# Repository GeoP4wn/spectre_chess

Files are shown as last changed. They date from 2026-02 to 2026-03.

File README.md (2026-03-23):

# Spectre Chess
---
## Overview
---
This is very much still a work in progress. The best place to start is the technical report (particularly the pictures at the end of the document) and the other documents in the docs folder.

This project is designed to be a robotic chessboard constrained to an external height of 60mm. It features an H-bot gantry to move an electromagnet, which in turn moves the chess pieces.
The main computing is done by a Raspberry Pi. The Raspberry Pi controls two ESP32s. One is responsible for the motors and magnets, the other is responsible for the sensors, LEDs and buttons.

AI Disclosure: Generative AI was used to build the basic structure and async loop of the codebase

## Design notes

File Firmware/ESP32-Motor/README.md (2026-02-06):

# ESP32 Motor Controller Firmware

## Overview
This firmware runs on the ESP32-S3 responsible for H-Bot gantry control, electromagnet actuation, and fan management.

## Hardware Responsibilities
- ✅ Control 2x TMC2209 stepper drivers (H-Bot kinematics)
- ✅ Home gantry using limit switch
- ✅ Control 4x electromagnets via MOSFETs
- ✅ PWM control of 4x cooling fans
- ✅ Communicate with Raspberry Pi via UART (JSON protocol)

## Pin Assignments

### Stepper Motors (TMC2209)
| Pin | Function | Description |
|-----|---|---|
| GPIO2 | MOTOR_A_STEP | Step pulses for Motor A |
| GPIO3 | MOTOR_A_DIR | Direction for Motor A |
| GPIO4 | MOTOR_A_EN | Enable for Motor A (active LOW) |
| GPIO5 | MOTOR_A_UART | Single-wire UART (with 1kΩ resistor) |
| GPIO6 | MOTOR_B_STEP | Step pulses for Motor B |
| GPIO7 | MOTOR_B_DIR | Direction for Motor B |
| GPIO8 | MOTOR_B_EN | Enable for Motor B (active LOW) |
| GPIO9 | MOTOR_B_UART | Single-wire UART (with 1kΩ resistor) |

### Electromagnets (MOSFET Control)
| Pin | Function | Description |
|-----|---|---|
| GPIO16 | MAGNET_1 | Electromagnet 1 gate (via 10kΩ pulldown) |
| GPIO17 | MAGNET_2 | Electromagnet 2 gate |
| GPIO18 | MAGNET_3 | Electromagnet 3 gate |
| GPIO19 | MAGNET_4 | Electromagnet 4 gate |

### Limit Switch
| Pin | Function | Description |
|-----|---|---|
| GPIO32 | LIMIT_SWITCH | Homing limit switch (active LOW) |

### Fans (PWM Control)
| Pin | Function | Description |
|-----|---|---|
| GPIO25 | FAN_1 | Fan 1 PWM (via level shifter to 5V) |
| GPIO26 | FAN_2 | Fan 2 PWM |
| GPIO27 | FAN_3 | Fan 3 PWM |
| GPIO33 | FAN_4 | Fan 4 PWM |

### UART Communication
| Pin | Function | Description |
|-----|---|---|
| GPIO1 (RX) | UART_RX | Receive from Raspberry Pi |
| GPIO3 (TX) | UART_TX | Transmit to Raspberry Pi |

## Dependencies
```ini
bblanchon/ArduinoJson@^6.21.3
teemuatlut/TMCStepper@^0.7.3
```

## H-Bot Kinematics Explained

### What is H-Bot?
H-Bot is a motion system where **both motors affect both X and Y axes**. Unlike traditional XY systems where one motor moves X and another moves Y, H-Bot uses a clever belt arrangement.

### Motor Coordination
```
To move +X: Motor A forward + Motor B forward
To move +Y: Motor A forward + Motor B backward
To move -X: Motor A backward + Motor B backward
To move -Y: Motor A backward + Motor B forward
```

### Mathematical Model
```
stepsA = stepsX + stepsY
stepsB = stepsX - stepsY
```

Inverse:
```
stepsX = (stepsA + stepsB) / 2
stepsY = (stepsA - stepsB) / 2
```

### Advantages
- ✅ Low moving mass (motors are stationary)
- ✅ Compact vertical profile (both belts in same plane)
- ✅ Good for speed and precision
- ✅ Perfect for our <45mm height constraint

### Disadvantages
- ⚠️ More complex firmware
- ⚠️ Requires synchronized motor control
- ⚠️ Belt tension is critical

## Communication Protocol

### Messages FROM ESP32 to Pi

#### Status
```json
{
  "type": "status",
  "status": "ready",
  "controller": "motor",
  "message": "Motor controller initialized"
}
```

```json
{
  "type": "status",
  "status": "homed",
  "controller": "motor",
  "message": "Gantry homed to (0, 0)"
}
```

#### Position Update
```json
{
  "type": "position",
  "x": 165.5,
  "y": 220.0,
  "homed": true
}
```

### Messages TO ESP32 from Pi

#### Home Gantry
```json
{
  "cmd": "home"
}
```

#### Move to Absolute Position
```json
{
  "cmd": "move_absolute",
  "x": 200.0,
  "y": 150.0,
  "speed": 5000
}
```

#### Move Relative
```json
{
  "cmd": "move_relative",
  "dx": 10.0,
  "dy": -5.0
}
```

#### Electromagnet Control
Turn on specific magnet:
```json
{
  "cmd": "magnet_on",
  "magnet": 1
}
```

Turn on all magnets:
```json
{
  "cmd": "magnet_on"
}
```

Turn off:
```json
{
  "cmd": "magnet_off",
  "magnet": 1
}
```

#### Fan Control
```json
{
  "cmd": "set_fan",
  "fan": 1,
  "speed": 200
}
```

#### Emergency Stop
```json
{
  "cmd": "stop"
}
```

#### Get Current Position
```json
{
  "cmd": "get_position"
}
```

## TMC2209 Configuration

### Current Settings
- **Run current**: 500mA RMS (for 0.7A NEMA17)
- **Hold current**: 200mA RMS (reduced when stationary)
- **Microstepping**: 16 (1/16 step)
- **Mode**: StealthChop (silent operation)

### Why StealthChop?
- 🔇 Near-silent operation
- ✅ Smooth motion at low speeds
- ✅ No tuning required
- ⚠️ Less torque at very high speeds (not an issue for chess board)

### UART Communication
TMC2209 uses **single-wire half-duplex UART**:
- 1kΩ resistor on RX pin prevents short circuit
- ESP32 TX and RX share same pin via resistor
- Address switches (MS1_AD0, MS2_AD1 on driver):
  - Motor A: Address 0b00
  - Motor B: Address 0b01

## Motor Calibration

### Steps Per MM Calculation
```
Pulley diameter: 20 teeth × 2mm = 40mm circumference
Belt pitch: GT2 (2mm)
Circumference: 40mm × π ≈ 125.66mm

Steps per revolution: 200 (1.8° stepper)
Microstepping: 16
Total steps per rev: 200 × 16 = 3200 steps

Steps per mm: 3200 / 125.66 ≈ 25.5 steps/mm
```

**Default in firmware: 80 steps/mm** (adjust based on your actual pulley size)

### Speed Settings
- **Default speed**: 2000 steps/sec (≈78mm/sec with 25.5 steps/mm)
- **Max speed**: 8000 steps/sec (≈314mm/sec)
- **Homing speed**: 500 steps/sec (slower for safety)

## Homing Sequence

1. **Move towards limit switch** (both motors reverse)
2. **Wait for trigger** (limit switch goes LOW)
3. **Stop immediately**
4. **Back off 100 steps** (move away from switch)
5. **Set position to (0, 0)**
6. **Mark as homed**

## Electromagnet Circuit

### MOSFET Switching
- **MOSFET**: IRFL44N (N-channel, logic level)
- **Gate resistor**: 10kΩ pulldown (prevents firing during boot)
- **Flyback diode**: 1N4007 (protects against back-EMF)
- **Load**: P25/20 electromagnet (12V, ~1A)

### Control Logic
```
GPIO HIGH (3.3V) → MOSFET ON → Magnet energized
GPIO LOW (0V)    → MOSFET OFF → Magnet off
```

### Why Pulldown?
During ESP32 boot, GPIOs are in high-impedance state. Without pulldown, the gate could float HIGH and accidentally energize magnets. The 10kΩ pulldown ensures MOSFET stays OFF until explicitly commanded.

## Building and Uploading

### Using PlatformIO CLI
```bash
cd ESP32-Motor
pio run --target upload
pio device monitor
```

### Using PlatformIO IDE
1. Open folder in VS Code with PlatformIO extension
2. Click "Upload" button
3. Click "Serial Monitor" button

## Testing

### 1. Basic Boot Test
After upload, check serial monitor:
```
=== ESP32 Motor Controller Starting ===
Configuring TMC2209 drivers...
TMC2209 drivers configured
Driver A current: 500
Driver B current: 500
Pins configured
Setup complete. Ready for commands.
```

### 2. Driver Communication Test
Verify TMC2209 UART is working:
- Check "Driver A current: 500" appears
- If shows 0 or error, check UART wiring

### 3. Manual Movement Test (NO LOAD)
**⚠️ Remove belt before this test!**

Send via Serial Monitor:
```json
{"cmd":"move_absolute","x":10,"y":0,"speed":1000}
```

Motors should turn slowly.

### 4. Homing Test
**WITH limit switch connected:**
```json
{"cmd":"home"}
```

Should see:
```
Starting homing sequence...
Limit switch triggered
Homing complete
```

### 5. Electromagnet Test
```json
{"cmd":"magnet_on","magnet":1}
```

Should hear relay/magnet click. Verify with multimeter: 12V across magnet.

### 6. Fan Test
```json
{"cmd":"set_fan","fan":1,"speed":200}
```

Fan should spin up.

## Troubleshooting

### Motors don't move
1. **Check enable pins** - Should be LOW to enable
2. **Check TMC2209 power** - Need 12V to VM pin
3. **Check UART communication** - Should see current readback
4. **Check motor wiring** - Coil pairs must be correct

### Motors move wrong direction
Swap direction logic in firmware or physically swap one coil pair.

### Homing doesn't work
1. **Test limit switch** - Should read HIGH when open, LOW when closed
2. **Check direction** - Motors should move toward switch
3. **Verify switch is in (0,0) corner**

### Electromagnets won't turn on
1. **Check 12V power supply**
2. **Verify MOSFET orientation** - Drain to +12V, Source to magnet
3. **Test GPIO directly** - Should read 3.3V when on
4. **Check flyback diode** - Stripe toward +12V

### TMC2209 gets hot
- Reduce current: `driverA.rms_current(400);`
- Add heatsink to driver
- Verify motor current rating

### Motors skip steps
- Increase current (up to motor rating)
- Reduce speed
- Check belt tension
- Verify acceleration isn't too high

## Calibration Procedure

### 1. Mechanical Setup
- Ensure belts are properly tensioned (should "twang" when plucked)
- Verify pulleys are tight on motor shafts
- Check that gantry moves smoothly by hand

### 2. Steps/MM Calibration
```cpp
// In firmware, adjust STEPS_PER_MM
#define STEPS_PER_MM  80  // Start here

// Test: Command 100mm movement
{"cmd":"move_absolute","x":100,"y":0}

// Measure actual distance traveled
// Adjust STEPS_PER_MM = (commanded / actual) * current
```

### 3. Speed Tuning
Start slow and increase:
```json
{"cmd":"move_absolute","x":200,"y":200,"speed":1000}
{"cmd":"move_absolute","x":0,"y":0,"speed":2000}
{"cmd":"move_absolute","x":200,"y":200,"speed":5000}
```

Find max speed where no steps are lost.

### 4. Acceleration Tuning
Currently not implemented (constant speed). Future enhancement.

## Power Requirements

- **Motors**: 12V, 0.7A each = 16.8W
- **Electromagnets**: 12V, 1A each × 4 = 48W (worst case, all on)
- **Fans**: 12V, 0.15A each × 4 = 7.2W
- **ESP32**: 3.3V, 0.2A = 0.66W
- **Total**: ~73W at full load

Recommended: **12V 10A power supply** for safety margin.

## Safety Features

### Implemented
- ✅ Position limits (won't move beyond MAX_X_MM, MAX_Y_MM)
- ✅ Homing required before movement
- ✅ Emergency stop command
- ✅ Pulldown resistors on MOSFET gates

### To Add (Future)
- [ ] Stall detection via TMC2209
- [ ] Soft limits
- [ ] Current monitoring
- [ ] Thermal protection
- [ ] Watchdog timer

## Future Enhancements

- [ ] Acceleration/deceleration curves
- [ ] Multi-segment path following
- [ ] Automatic stall recovery
- [ ] Position feedback verification
- [ ] Coordinated multi-axis circular interpolation
- [ ] Backlash compensation

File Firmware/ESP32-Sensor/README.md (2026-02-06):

# ESP32 Sensor Controller Firmware

## Overview
This firmware runs on the ESP32-S3 responsible for sensor scanning, LED control, and button input monitoring.

## Hardware Responsibilities
- ✅ Scan 64 Hall Effect sensors (8x8 matrix) via 4x CD74HC4067 multiplexers
- ✅ Control 64 WS2812B RGB LEDs for board visualization
- ✅ Read 6 physical buttons
- ✅ Read 2 rotary encoders with buttons
- ✅ Communicate with Raspberry Pi via UART (JSON protocol)

## Pin Assignments

### Multiplexer Control (Shared)
| Pin | Function | Description |
|-----|---|---|
| GPIO2 | MUX_S0 | Multiplexer select bit 0 (all 4 muxes) |
| GPIO3 | MUX_S1 | Multiplexer select bit 1 |
| GPIO4 | MUX_S2 | Multiplexer select bit 2 |
| GPIO5 | MUX_S3 | Multiplexer select bit 3 |
| GPIO16 | MUX_EN | Multiplexer enable (active LOW) |

### Multiplexer Outputs
| Pin | Function | Handles |
|-----|---|---|
| GPIO17 | MUX1_OUT | Ranks 0-1 (squares a1-h2) |
| GPIO18 | MUX2_OUT | Ranks 2-3 (squares a3-h4) |
| GPIO19 | MUX3_OUT | Ranks 4-5 (squares a5-h6) |
| GPIO21 | MUX4_OUT | Ranks 6-7 (squares a7-h8) |

### LEDs
| Pin | Function | Description |
|-----|---|---|
| GPIO22 | LED_DATA | WS2812B data line (64 LEDs) |

### Buttons
| Pin | Function | Description |
|-----|---|---|
| GPIO25 | BTN1 | Clock button 1 (top left) |
| GPIO26 | BTN2 | Clock button 2 (top right) |
| GPIO27 | BTN3 | Side button 1 |
| GPIO32 | BTN4 | Side button 2 |
| GPIO33 | BTN5 | Side button 3 |
| GPIO34 | BTN6 | Side button 4 |

### Rotary Encoders
| Pin | Function | Description |
|-----|---|---|
| GPIO35 | ENC1_A | Encoder 1 channel A |
| GPIO36 | ENC1_B | Encoder 1 channel B |
| GPIO39 | ENC1_BTN | Encoder 1 button |
| GPIO14 | ENC2_A | Encoder 2 channel A |
| GPIO12 | ENC2_B | Encoder 2 channel B |
| GPIO13 | ENC2_BTN | Encoder 2 button |

### UART Communication
| Pin | Function | Description |
|-----|---|---|
| GPIO1 (RX) | UART_RX | Receive from Raspberry Pi |
| GPIO3 (TX) | UART_TX | Transmit to Raspberry Pi |

## Dependencies
```ini
adafruit/Adafruit NeoPixel@^1.11.0
bblanchon/ArduinoJson@^6.21.3
```

## Communication Protocol

### Messages FROM ESP32 to Pi

#### Sensor Update
Sent when board state changes.
```json
{
  "type": "sensor_update",
  "sensors": [
    [false, true, true, true, true, true, true, false],
    [true, true, true, true, true, true, true, true],
    [false, false, false, false, false, false, false, false],
    ...
  ]
}
```

#### Button Event
```json
{
  "type": "button",
  "button": 1,
  "state": "pressed"
}
```

#### Encoder Event
```json
{
  "type": "encoder",
  "encoder": 1,
  "delta": -2
}
```

#### Status
```json
{
  "type": "status",
  "status": "ready",
  "controller": "sensor"
}
```

### Messages TO ESP32 from Pi

#### Scan Sensors
Request immediate sensor scan.
```json
{
  "cmd": "scan_sensors"
}
```

#### Highlight Squares
Light up specific squares.
```json
{
  "cmd": "highlight_squares",
  "squares": [[3, 4], [4, 4]],
  "color": [0, 255, 0],
  "duration": 2000
}
```

#### Flash All LEDs
Flash all LEDs (error indication).
```json
{
  "cmd": "flash_all",
  "color": [255, 0, 0],
  "count": 3
}
```

#### Set LED Theme
```json
{
  "cmd": "set_theme",
  "theme": "classic"
}
```

#### LEDs Off
```json
{
  "cmd": "leds_off"
}
```

#### Set Brightness
```json
{
  "cmd": "set_brightness",
  "brightness": 128
}
```

## Sensor Scanning Logic

The firmware scans all 64 sensors every 100ms:

1. **Loop through each square** (8x8 = 64 total)
2. **Calculate multiplexer and channel**:
   - Multiplexer index = rank ÷ 2 (0-3)
   - Channel = (rank mod 2) × 8 + file (0-15)
3. **Set channel select pins** (S0-S3)
4. **Read from appropriate MUX output pin**
5. **Invert result** (AH3503 is active LOW)
6. **Compare with last state** - if changed, send update

## LED Layout

LEDs are arranged in a serpentine pattern:
- **Rank 0** (a1-h1): Left to right (indices 0-7)
- **Rank 1** (a2-h2): Right to left (indices 8-15)
- **Rank 2** (a3-h3): Left to right (indices 16-23)
- And so on...

This minimizes wiring length for WS2812B strip.

## Building and Uploading

### Using PlatformIO CLI
```bash
cd ESP32-Sensor
pio run --target upload
pio device monitor
```

### Using PlatformIO IDE
1. Open folder in VS Code with PlatformIO extension
2. Click "Upload" button
3. Click "Serial Monitor" button

## Testing

### 1. Basic Boot Test
After upload, check serial monitor:
```
=== ESP32 Sensor Controller Starting ===
Pins configured
LEDs initialized
Setup complete. Ready for commands.
```

### 2. LED Test
LEDs should flash white briefly on boot.

### 3. Sensor Test
Place a magnet on the board and observe serial output:
```
Sensor update sent
```

### 4. Button Test
Press any button:
```
Button 1 pressed
Button 1 released
```

### 5. UART Test
Send from Pi:
```bash
echo '{"cmd":"scan_sensors"}' > /dev/ttyUSB0
```

Should receive JSON response.

## Troubleshooting

### LEDs don't light up
- Check 5V power supply to LED strip
- Verify data pin connection (GPIO22)
- Ensure ground is common between ESP32 and LED strip

### Sensors not responding
- Verify 5V power to AH3503 sensors
- Check TXS0108E level shifter connections
- Ensure multiplexer enable (GPIO16) is LOW
- Test with multimeter: sensor output should be LOW when magnet present

### No UART communication
- Check TX/RX connections (they should cross: ESP32 TX → Pi RX)
- Verify baud rate matches (115200)
- Test with USB-to-serial adapter first

### Buttons always pressed / never pressed
- Buttons should be active LOW with pullup resistors
- Check wiring: one side to GND, other to GPIO
- Verify internal pullup is enabled

## Hardware Notes

### Level Shifters
The TXS0108E shifts between:
- **A-side (VCCA)**: 3.3V (ESP32 logic)
- **B-side (VCCB)**: 5V (sensor outputs)

Connect sensor outputs to B-side, ESP32 GPIOs to A-side.

### Hall Effect Sensors
AH3503 sensors:
- **Pin 1 (VCC)**: 5V
- **Pin 2 (GND)**: Ground
- **Pin 3 (VOUT)**: Open drain output (active LOW)
  - Needs pull-up resistor to 5V (typically 10kΩ)
  - LOW when magnet present
  - HIGH (pulled up) when no magnet

### Multiplexer Channel Mapping
Each CD74HC4067 handles 16 sensors (2 ranks × 8 files):

**MUX 1** (Ranks 0-1):
- Channel 0-7: a1, b1, c1, d1, e1, f1, g1, h1
- Channel 8-15: a2, b2, c2, d2, e2, f2, g2, h2

**MUX 2** (Ranks 2-3):
- Channel 0-7: a3, b3, c3, d3, e3, f3, g3, h3
- Channel 8-15: a4, b4, c4, d4, e4, f4, g4, h4

And so on for MUX 3 and MUX 4.

## Power Consumption

Estimated current draw:
- ESP32-S3: ~200mA (WiFi off)
- 64x WS2812B LEDs (all white, full brightness): ~3.8A
- Hall Effect sensors: ~64mA
- **Total**: ~4.1A at 5V

Use a quality 5V 5A power supply!

## Future Enhancements

- [ ] Automatic LED animations during idle
- [ ] Configurable scan interval
- [ ] Sensor calibration routine
- [ ] Button long-press detection
- [ ] LED brightness auto-adjustment
- [ ] Power-saving mode

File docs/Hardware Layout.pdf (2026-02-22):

## Raspberry Pi

Hardware | Software
Microphone | Voice Recognition (https://maker.pro/raspberry-pi/tutorial/the-best-voice-recognition-software-for-raspberry-pi)
LCD Screen + Touch | User Interface
| Touch Recognition
| BoardState
| ChessEngine
| UserDatabase
| MoveEvaluation

## Motor ESP32

Hardware | Software
Motor | Fan Control
Electromagnet | ChessMoveToMotorMovement
Fans | ElectromagnetControl

## Sensor ESP32

Hardware | Software
Buttons and Rotary Encoder | ButtonPresses
Hall Effect Sensors | SensorReadOut
LEDs | MoveToLEDLight

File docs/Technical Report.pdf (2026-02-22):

# Automated Chessboard: A Distributed IoT System with H-Bot Kinematics

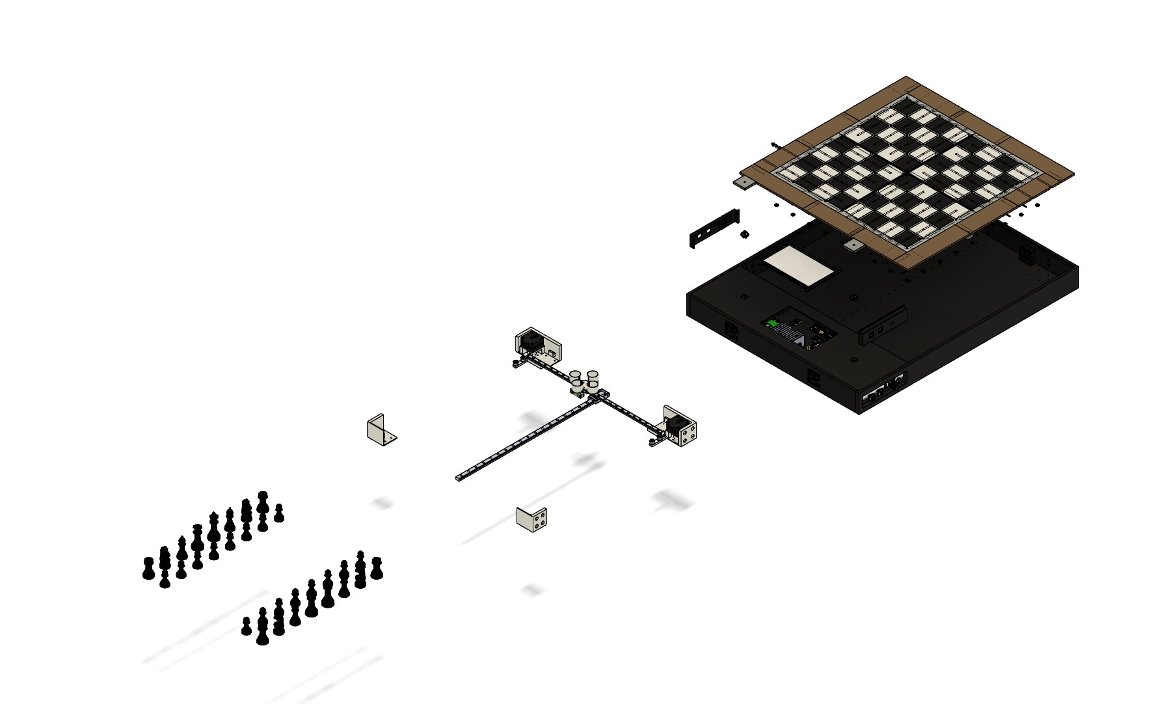
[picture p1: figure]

## Abstract

This report describes the design and implementation of a smart robotic chessboard utilizing an H-Bot gantry system. The system utilizes an H-Bot gantry architecture constrained to an internal 45mm height profile, orchestrating movement via a distributed network of microcontrollers and a single-board computer. Key contributions include a low-friction material interface for 3D-printed surfaces, a custom JSON-over-UART communication protocol, and a local, offline software stack featuring real-time WebSockets and voice recognition.

## Introduction

Traditionally, chess is a game played between two human players. Recent technological advances have enabled to play against chess engines or other humans online. This enables to play chess whenever one likes. However, many people feel a lack of haptic feedback when moving pieces and screeens can be exhausting when used over long periods of times. This was the reason for the developement of smart chess boards. The first step were boards that were able to calculate follow up moves, but changes in the pieces position had to be manually registered by pressing buttons. A novelty were LED chess boards that feautered sensor technology and feedback through LED lights inside of the squares. The most modern form of a smart chess board are fully automatic boards which in adition to sensors also have a mechanical system that moves the chess pieces. This is often achieved by a moving electromagnet and magnets in the bottom of the chess pieces that also trigger reed or hall effect sensors.
Many adaptations from makers all around the world have been made for afore mentioned technology. However most self built gantry systems feature an exterior height of more than 100mm making it impractical to use these boards on common tables. An additional problem is that the motors driving the mechanism can be quite loud. Sadly many makers don't document their build process well and only release parts of their work, if at all.
Naturally there also are commercial automatic chessboards. Commercial boards can offer premium technology like chess pieces that have tiny motors built inside of them, individual piece recognition through NFC,RFID or LC circuits and access to otherwise private APIs of popular plattforms. Accompaning those advantages often are very closed ecosystems and great accuisition costs. In some case even subscription models.
The automatic chess board described in this report aims to be an open source plattform that can offer all the features a chess player would want to have in their board. It also aims to be buildable at a modest price that still enables good quality. This is achieved by taking inspiration from existing commercial and self built smart chess boards and innovating on top of them. As soon as the first final version of the chess board will be finished all CAD files of the 3d printed parts, the BOM, a devlog and the whole codebase will be published on GitHub.

## Related Work

Many adaptions of the automatic chess board exist. Listed here are the most influential on this project.

### Group A: Haptic/LED Only (Manual Movement)

ZyChess (Zyger)
The video about this project by Zyger was what inspired the making of this project in the first place. Zyger built a LED smart chessboard as an university project. It didn't feature any sensors, inputs had to be made by buttons. Zyger appeared to be heavily inspired by an instructable (https://www.instructables.com/DIY-Super-Smart-Chessboard-Play-Online-or-Against-/) posted by Lewis "Diy Machines".
Custom Electric Chessboard (Olivier Mercier)
Olivier Mercier customized a store bought chessboard to feature sensors and LED lights. Olivier used the Lichess API to play against engines or players, which was controlled by an external touch display. It inspired the placement of the LEDs around the squares instead of in the middle of them.

### Group B: Automated/Robotic Systems

Phantom Chessboard
Coming in at a retail price of 800 Dollars this board was first developed by a maker before reaching 2 million dollars in funding on kickstarter. Phantom aims to provide a premium expirience. It inspired this project to start with a SCARA mechanism before switching to a H-bot mechanism due to scarcity of parts and height of the mechanism.
Gambit
Gambit aims to be an affordable self built chess board and was inspired by Phantom. Gambit changed the SCARA mechanism to a H-bot mechanism, an adaptation of which is used in this project. Gambit posted their progress on Hackaday, still a lot of the files and progress reports are missing, which ended up being a great frustration to this project.
Automated-Chessboard (Greg06)
This self built project incoporates a CoreXY Gantry System to automatically move the chess pieces. It features a button triggered turn system, a small screen and Staunton 3 sized chess pieces. The case of this project was created out of foamboard. Documentation is well written and complete, it even explains some of the theory behind mechanisms and software. "Automated-Chessboard" uses reed switches instead of hall effect sensors and a single Arduino Nano instead of two seperate microcontrollers with one single board computer as an orchestrator.
The main improvement on this design in this project is the lower vertical form factor (60%). The screen and additional computing power are also advantages but increase the footprint of the project.

## Problem Statement

The primary objective of this project is to develop an open-source, reproducible automated chessboard that balances high-fidelity user experience with cost-effective manufacturing. Mechanical Strategy & Motion Kinematics
- Height Limitation: A critical design constraint is the vertical form factor, which must remain below 60mm—a significant reduction compared to standard CoreXY systems which typically range from 100mm to 120mm.
- Homing: The position of the piece moving carriage has to be known
- Pathfinding Complexity: Implementing the Knight’s jump and Castling requires complex pathfinding algorithms to navigate around occupied squares, as physical pieces cannot "jump" over one another in a 2D plane. Castling introduces a multi-step execution requirement where two pieces must be moved sequentially without collision.
- Piece Management: When capturing pieces the captured piece has to move off the board first and be put alongside other captured pieces without them being in the way of the game. Automated capture logic requires a dedicated "graveyard" zone and a non-obstructive path to exit the 64-square play area.
- Heat Management: A closed case will retain heat well.
- Friction: Moving PETG chess pieces across a textured surface of the same material has to overcome a lot of friction.
Electronical Architecture & Signal Integrity
- Signal Identification: Utilizing a Hall Effect sensor matrix allows for binary occupancy detection but introduces the challenge of state tracking, as the sensors cannot natively distinguish between piece types.
- Hall Effect Sensors often have Open Drain ouputs. A microcontroller will only catch electrical noise as the wire will act like an antenna.
- I/O Multiplexing: With 64 sensor inputs and limited GPIO pins on the ESP32/Pi, an efficient multiplexing or shift-register architecture is required.
- Power Integrity: The system must manage a "noisy" electrical environment where inductive loads (NEMA motors and electromagnets) create back-EMF spikes that threaten sensitive 3.3V logic and LED signal integrity.
- Voltage Domain Management: The architecture must efficiently step down 12V (motors/magnets) to 5V (LEDs/Sensors) and 3.3V (Logic) while maintaining a common ground.
- Electromagnets: The electromagnets operate at 12V but a GPIO pin can provide 3.3V
- Motor Driver Communication: modern motor drivers only have a single UART pin but most microcontrollers have seperate rx and tx. If the two pins were just connected to one pin the microcontroller could short circuit its own rx pin when the driver would talk back whilst sending.

Logic Flow & Data Management
- Compute Orchestration: The system must handle high-compute tasks (chess engine, Voice Recognition) alongside low-latency hardware interrupts for motor control.
- Node Communication: The main orchestrator must be able to communicate effectively to and from its nodes
- Latency & Connectivity: To ensure a "reactive" feel, the system must bypass traditional high-latency HTTP protocols that break the immersion of the "live" board.
- Sovereign Operation: The board must support offline edge-computing for privacy and usability in environments without internet access.
- Data Persistence: In a multi-user environment, the system must manage conflicting preferences and maintain long-term game records.
- Online Play: Some users might wish to remotely play other humans, public puzzles or specific bots they already are familiar with.

## Technical Solution

The detailed documentation of the development process aims to achieve a good open source documentation. To provide a good user expirience a lot of customazability is given trough settings. By moving most settings to a web user interface, cluttering of the main 7" screen is avoided. The screen UI can be controlled by both touch and buttons. Also a chess clock is directly integrated into the side bay of the chess board.
To keep manufacturing and prototyping costs low many components are 3d printed.
Mechanical Strategy & Motion Kinematics
- H-Bot Gantry Architecture: To meet the strict <60mm height constraint, an H-Bot kinematics system is utilized. Unlike traditional XY gantries, the H-Bot keeps motors stationary at the frame corners, allowing for a significantly thinner carriage profile and simplified belt routing in a single horizontal plane. It is homed with a limit switch that is mounted on the motor bracket.
- Collision-Aware Pathfinding: To handle the "Knight" and "Castling" maneuvers, the system employs a coordinate-based pathfinding algorithm. This logic calculates "indirect" paths—moving pieces along the borders of squares—to avoid collisions with stationary pieces, effectively simulating a "jump" in a 2D physical space.
- Chess Piece Size: To enable the afore mentioned pathfinding algorithm piece size was chosen at 80% tournament size. This way most pieces are smaller than half the size of the squares.
- Automated Displacement Logic: For piece captures, a dedicated sub-routine calculates a trajectory to the "graveyard" zone. The algorithm prioritizes paths through empty squares to ensure the captured piece does not disturb the active game state.
- Heat Management: To provide airflow 40mm server fans can be used
- Friction: The use of a PTFE Base underneath each chess piece will provide a durable low friction surface.

Electronical Architecture & Signal Integrity
- Distributed Processing Model: The system architecture is divided into three functional domains: an Orchestrator for high-level logic, a Motion Controller for deterministic timing, and a Sensing Node for occupancy detection. This separation prevents "blocking" during heavy AI computations.
- Node Communication: UART PROTOCOL TODOOOOOOOOOOOOOO
- Software-Defined Piece Identification: Since Hall Effect sensors only provide binary occupancy data, the system maintains a Digital Twin of the board state. By comparing the "before" and "after" sensor matrix scans, the logic identifies which specific piece was moved based on the starting coordinate.

- Multiplexed Sensing Matrix: To overcome I/O limitations, the 64 sensors are organized into a scanned grid. This allows for a full board update using significantly fewer microcontroller pins than a direct-mapped approach.
- Pull-up Resistors: To deal with the open drain output a pull-up resistor is connected to the line. This way a power signal will be pushed to 5V upon high impedence. The signal is then directed through a logic-level shifter to the microcontroller.
- Inductive Load Isolation: To protect sensitive logic, the power architecture implements a tiered regulation system. Inductive components (motors and magnets) are isolated from the logic rail using protection diodes and filtering capacitors to suppress back-EMF spikes.
- Voltage Domain Management: To step down from 12V to 5V a buck converter is used. Both the single board computer and microcontrollers step down from 5V to 3.3V. To enable the microcontrollers to read the 5V sensor output, logic level shifters are used. This also enables the fans to receive a 5V PWM signal from a 3.3V GPIO pin.
- Electromagnets: To provide 12V the GPIO Pin is wired to a MOSFET which then switches power to the electromagnet. To have the default state of the MOSFET on off, a pull-down resistor is also connected to it. This prevents the electromagnet to accidentally fire during booting when the GPIO pins are in a high-impedance state.
- Motor Driver Communication: By placing a 1k resistor on the rx pin the circuit is protected. This enables half-duplex communication on a single pin on the motor driver. Logic Flow & Data Management
- Asynchronous Event Loop: The central software architecture is built on an event-driven loop. This allows the system to poll sensors, process voice inputs, and update the user interface concurrently without serial bottlenecks.
- Persistent Bi-directional Communication: To eliminate the latency inherent in request-response models, the system establishes a persistent "tunnel" for data. This ensures that a physical move is reflected on the digital interface in near real-time.
- Edge-Computing Architecture: All critical functions—including the chess engine and voice-to-command interpretation—are processed locally on the hardware. This ensures operational sovereignty and eliminates dependencies on external cloud services or internet connectivity.
- Relational Data Modeling: A structured data model is used to separate user preferences from game state. This allows for multi-user support where individual settings (like motor speed or difficulty) are stored independently of the ongoing game history.
- Online Play: One of the biggest online chess providers offers a very capable API.

## Implementation

The publication plattform for the open source code will be git hub. It provides neatless integration with git, which will be used with this project, and has a large user base.
The button layout is two buttons on the top of the sidebay and two additional ones on each side as well as one rotary encoder with a click function on each side. This was chosen to provide a direct path to the buttons on the top, as they will control the chess clock, whilst preserving a lot of button functionalities for further options.
To preserve structural integrity with 3d printed parts PETG filament was chosen as it is considered stronger than PLA.
Mechanical Strategy & Motion Kinematics
- H-Bot
- Motor Choice: Nema17 0.7A stepper motors were chosen for their size, strength and precision. To control the stepper motors TMC2226 drivers are used. They are silent and have better thermal values than TMC2209.
- Pulleys&Idlers Choice: Matching the common gt2 6mm belt, 20T gt2 6mm pulleys are fitted to the stepper motors. The idlers which are mounted on the 3d printed brackets direct the teethed side of the belt by 180 degrees. Therefore teethed 20T W6 B5 idlers were chosen which are bigger than the smooth 16T W6 B3 idlers on the end of the upper linear guide rail. The smaller idlers meet the smooth side of the belt and direct it by only 90 degrees.
- Linear Guide Rail Choice: For the base a 500mm MGN12H Rail is used. The upper rail is a 450mm MGN9H rail. This choice was made in reference to the Gambit project which successfully integrated a similar mechanism with these rails. The H-Bot of this project is slightly larger because this board uses a 5mm space for the LEDs between each square. Increasing the rail size by 50mm.
- Pathfinding: A specific pathfinding mechanism has not yet been chosen because of the project currently being in the beginning of software development.
- "Graveyard": To provide space for captured pieces the chess board features a 3d printed brim around the playing area. Along the long sides its size is 51.5mm, along the short sides 48.5mm.

Electronical Architecture & Signal Integrity
- Distributed Processing Model: For the calculation heavy single board computer a Raspberry Pi 4B 8GB is used for its power and price effectiveness. Two esp32s were chosen as hardware controllers. Mainly due to pin count and popularity. One of them is responsible for the multiplexed hall effect sensors, the buttons and rotary encoders as well as the LEDs. The other esp32 controlls the stepper motors and electromagnets as well as the fans.
- Hardware
- Electromagnets: To provide a lot of magnetic force, which drastically decreases with space, P25/20 electromagnets were chosen. They provide up to 8kg of magnetic force.
- Hall Effect Sensors: A digital hall effect sensor, like the A3144 provides better options to the project and is easier to work with than an analog one.
- Multiplexers: using an analog multiplexer is easy with microcontrollers and compatible with all technologies used in this project.
- Logic Level Shifters: The TXS0108E is a bi-directional logic level converter with enough chanels and also allows the control of the fans by stepping up from 3.3V to 5V.
- LEDS: WS2812Bs are at a managable logic level and are common in self built projects
- Microphone: The MS3625 was selected primarily for its ultra-compact surface-mount footprint.
- Wires: 18WAG is used for the main power lane before reaching the buck converter from which on most wire is 24AWG, with exeption for the sensor data lines that use 30AWG. These diameters should not limit any components from power and are all silicone coated to be flexible.
- Fans: The 40mm Arctic S4028-6K are small, quiet and provide a lot of airflow. They also are cost effective.
•
Logic Flow & Data Management
- Asynchronous Event Loop
1. BOOT (system startup, hardware checks, homing motors)
2. IDLE/MENU (Waiting for user login or game start)
3. HUMAN_TURN (Waiting for physical sensor changes)
4. ROBOT_TURN (Calculating and executing mechanical movements)
5. ERROR (illegal move detected or hardware fault)
6. GAME_OVER (display results, save stats)
- Logic Flow: The Sensing Node polls the Hall Effect matrix every 100ms. If a delta is detected, a JSON packet is sent to the Orchestrator, which verifies the move against the Stockfish-validated internal board state.

- Persistent Bi-directional Communication: A specific WebSocket Solution has not yet been chosen.
- Edge-Computing Architecture: To calculate the next move for the robot player Stockfish has been chosen as an engine. It is the most capable and popular engine and has adaptations for the Raspberry Pi.
- Relational Data Modeling: The user and game history database will run on SQLite. The Databse will be realtively small and SQLite is not as compute heavy and complex as MySQL.
- Online Play: Lychess can be accessed through the berserk library in Python.

## Discussion

The current state of the project is at the start of writing the software, which is why some software solutions were not yet fully describable in the implementation.
Because Gambit didn't specify many of their mechanical components certain assumptions had to be made. This means that the H-Bot assembly may need some prototyping before being able to be implemented fully.
The development of the H-Bot Smart Chessboard has highlighted several critical engineering trade-offs, particularly regarding manufacturing precision and system integration.
- Manufacturing Challenges: The 3D printing of the large frame components encountered significant thermal warping. This led to the partial failure of several dovetail connectors. While the initial prototype was salvaged using adhesive bonding along a straight-edge, this highlighted a limitation in the current design's print orientation. For future iterations, a segmented print strategy or the use of an enclosed printing environment for PETG would be required to maintain the tolerances necessary for the dovetail joints.
- Mechanical Integrity: The use of high-strength neodymium magnets for the side-bay assembly proved excellent for rapid prototyping and internal access. However, this choice compromises the structural "rigidity" required for transport; the lack of mechanical fasteners means the board cannot be lifted from the base without risking a collapse of the side walls. A hybrid approach using recessed 3x20mm wood screws is proposed for the final production model.
- Budgetary Analysis: The project exceeded the initial target budget of 300 CHF, reaching a total expenditure of approximately 500 CHF. This increase was driven by not incalculating some of the expenditures for tools, wires, filament, unforseen need of hardware like threaded inserts, resistors, capacitors, mosfets and similar. Despite this 66% increase, the system remains significantly more cost-effective than commercial automated boards, which often retail for 1,000 CHF or more.
- Software Complexity: The transition from hardware assembly to software implementation revealed a higher level of complexity than initially anticipated, particulary regarding the implemenation of the asynchrous event loop in code and working across multiple files and languages.

### 7.2 Conclusion

This project successfully demonstrated that a customazible automated chessboard can be housed within a compact 60mm vertical profile. A 40-50% reduction compared to standard CoreXY alternatives. The integration of an H-Bot gantry, a distributed processing model, and low-friction PTFE interfaces provides a viable foundation for a silent, responsive robotic system.

## Attachements

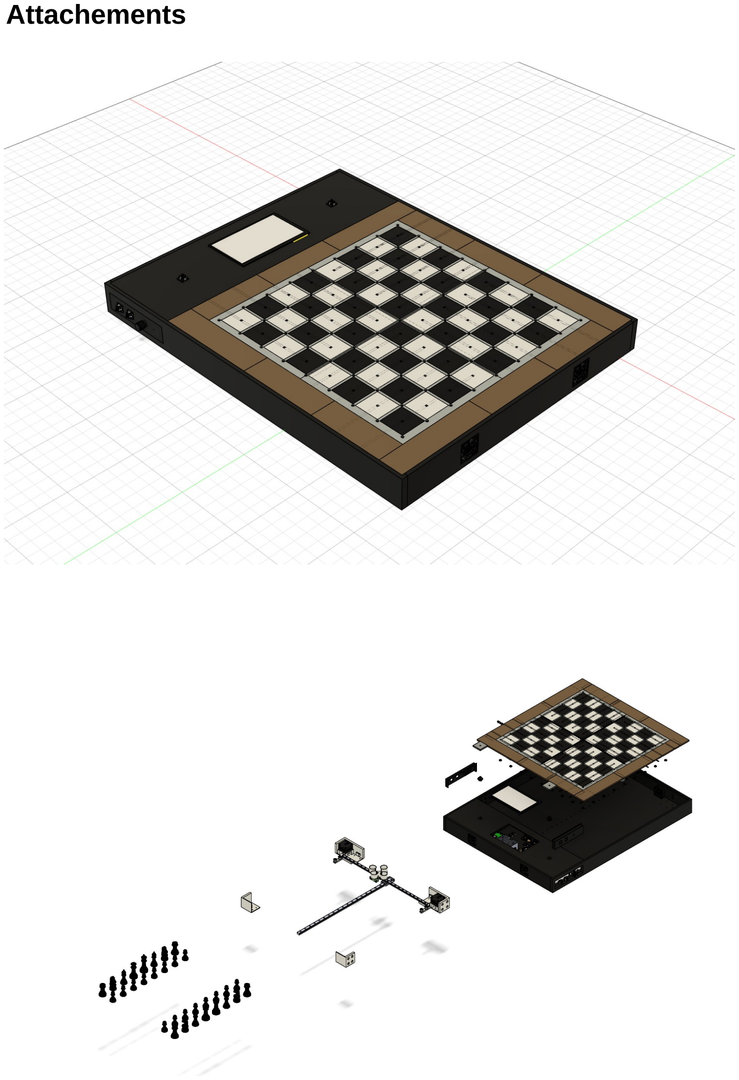
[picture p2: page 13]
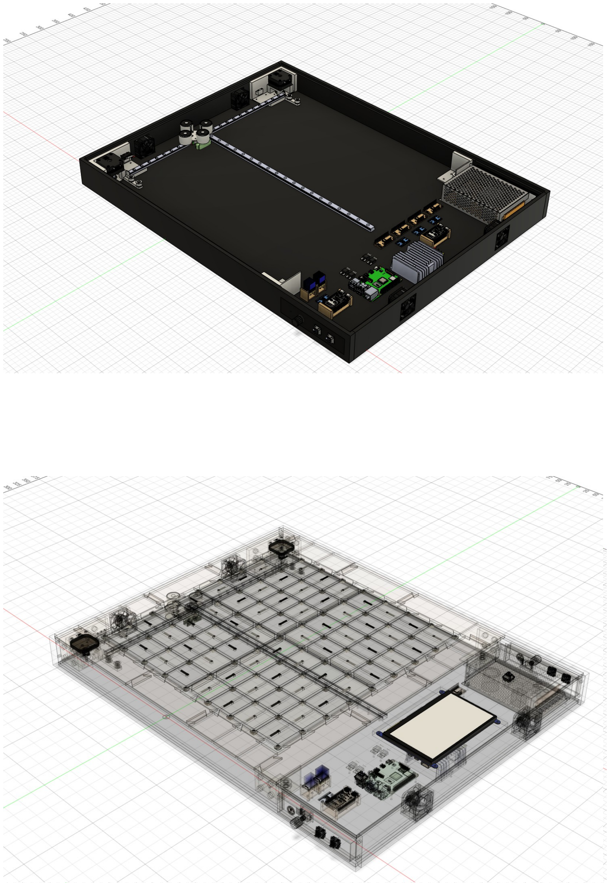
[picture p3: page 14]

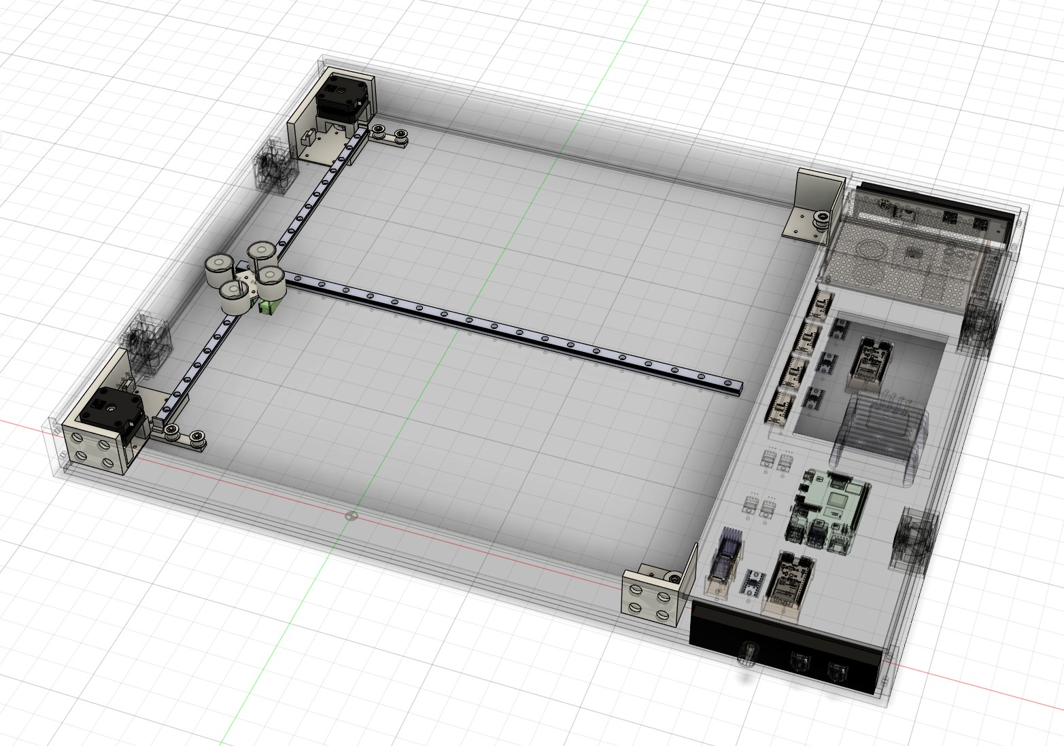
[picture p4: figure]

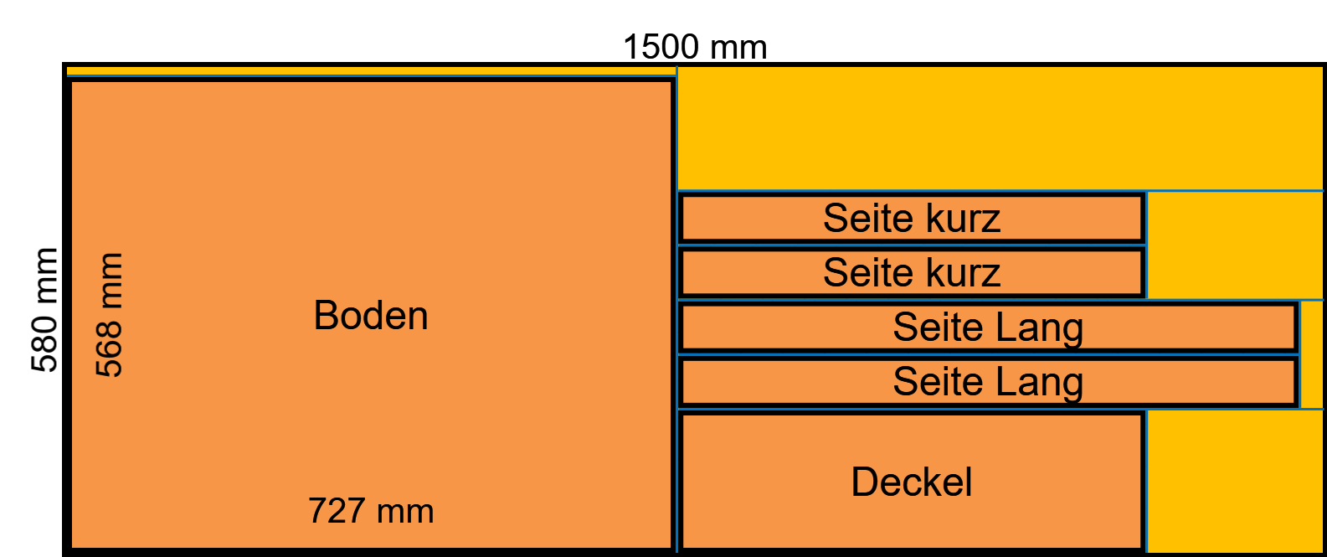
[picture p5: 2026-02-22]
docs/cutting_plan_wood.png

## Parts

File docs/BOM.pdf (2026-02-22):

BOM:
# | Description | Price | V/I

2 | ESP32-S3 N8R16 (https://www.ebay.ch/itm/389094824896?_skw=esp32-s3+n16r8&itmmeta=01KE4M9S39XN24NQXX51VVQJDA) | 10 | 5/0.2
66 | Hall Effect Sensors (A3144, unipolar digital) (https://www.ebay.ch/itm/385421037488) | 5 | 5/0.35
4 | CD74H4067 Multiplexers (https://www.ebay.ch/itm/295901370371?_skw=multiplexer&itmmeta=01KE4MF9D6RNKYRGM3JRVQRHTH) | 5 | 5/~0
2 | TXS0108E Logic Level Shifters (https://www.ebay.ch/itm/257256904199?_skw=Logic+Level+Shifter&itmmeta=01KE4M758QBXJ8J6JMYFMCYFCS) | 3 | 5/0.01
64 | WS2812B (https://www.ebay.ch/itm/356444567339?_skw=WS2812b&itmmeta=01KE4KZGPGFEFDQD5D96RWF3AZ) SMD LEDs | 11 | 5/3.2
2 | Rotary Encoder w/ switch (https://www.ebay.ch/itm/172434964618?_skw=rotary+encoder+with+click&itmmeta=01KE4HVHWF35ERB0YSHX6X6NSV) | 2 | 5/~0
4 | keyboard switches | | 5/~0
1 | 3,5" (https://www.ebay.ch/itm/401879960994?_skw=ILI9341&itmmeta=01KE4D9CYT854DK68JTTP3RBG9) LCD TFT SPI Touch Screeen | 15 | 5/0.16
1 | 12V PSU | 8 | :)
x | 1000 UF 6.3V capacitors | 4 | 6.3/~0 (leakage)
32+ 18 | 3x10mm N52 Magnets | 10 | :)
8 | 3x5mm N52 Magnets | 5 | :)
2 | 17HS4023 stepper motors | 20 | 12/1.4
2 | TMC2226 stepper motor driver | 14 | 6 or 12/0.015
4 | P25/20 electromagnet | 20 | 12/1.3 (only 1 at a time)
2 | 1N4007 schottky diode | 4
2 | MS3625 microphone | 5 | ~0
4 | conical springs (dont know which yet) | 5 | :)
1 | PTFE sheet | 20 | :)
1 | 5/7.5 A automotive fuse (for + psu terminal)
1 | Raspberry Pi 4B 4GB Ram | 50 | 5/1.3
1 | Raspberry Pi 4 Heat Sink | 7 | 0
1 | MGN12H 500mm Linear Rail | 20 | :)
1 | MGN9H 450mm Linear Rail | 22 | :)
1 | gt2 belt 6mm | 15 | :)
2 | 20T 6mm gt2 pulleys (5mm bore) | 5 | :)
2 | 20T W6 B5 idler pulley w/ T | 4 | :)
4 | 20T W6 B5 idler pulley w/o T | 4 | :)
1 | 12 to 5v buck converter (15/20A) | 15 | 12V/4.8 = 5V/10
1 | KW12-3 Limit Switch? | 5
4 | 16t gt2 6mm idlers no t (unsure about 16t or 20t) | 4
20 | M3 threaded inserts (buy directly from RAMPA!) (https://www.rampa.com/eu/en/RAMPA-INSERTS-TYPE-A/0013100010100) | 25
4 | Arctic S4028 | 25 | 12/0.4
0.6 | Multiplex board (incl. cutting service by | 70

m 2 | carpenter)
20 m | 30 AWG wire (red, black, 5m blue) | 7
20 m | 24 AWG wire (red, black, 5m blue) | 15
5m | 18AWG wire (red, black) | 7
2m | cable sleeve (could also 3d print a drag chain) | 5
10 | WAGO 221-415 | 10
4 | 1/4W 10K resistor | 4
2 | 100UF 25V Capacitor (motor drivers) | 2
2 | 1/4W 1k resistor | 2
4 | IRLZ44N MOSFET | 2
1 | 250x500x0.5mm ptfe sheet | 10
1 | Epoxy glue | 25
1 | Casting epoxy | 25
| total | | 5V 8.5 A 12V 7.9A

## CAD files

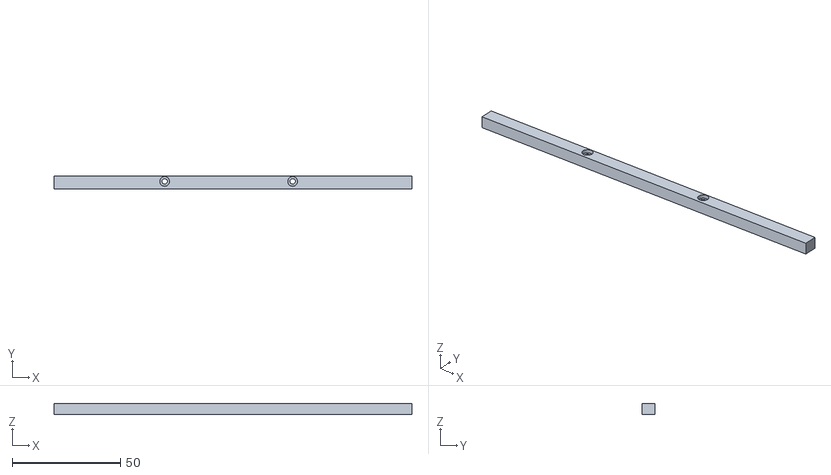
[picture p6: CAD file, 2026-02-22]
hardware/top_end_1.stl
165.0 x 6.00 x 5.00

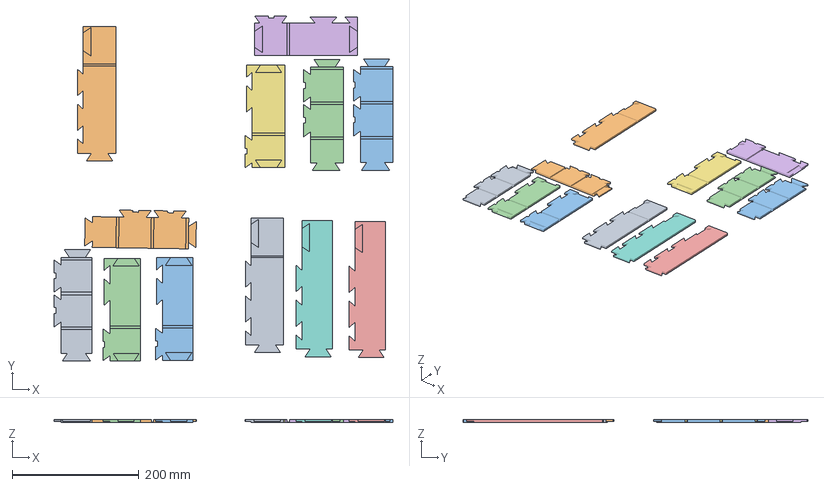
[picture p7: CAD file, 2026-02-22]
hardware/brim.3mf
534.3 x 544.0 x 5.00 mm
Brim x 51.5.stl x 2
Brim y 51.5.stl x 2
brim x 48.5.stl x 2
Brim z 51.5.stl x 2
Brim y 48.5.stl x 2
brim z 48.5.stl x 2

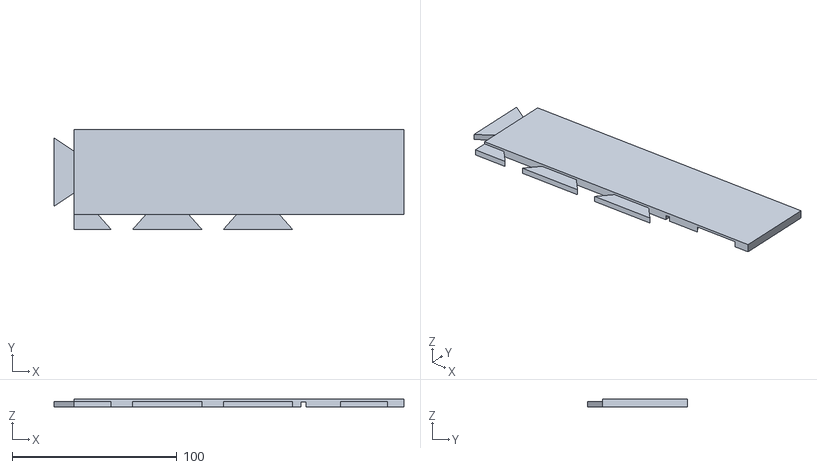
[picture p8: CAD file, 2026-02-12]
hardware/Brim x 51.5.stl
212.2 x 60.5 x 5.00

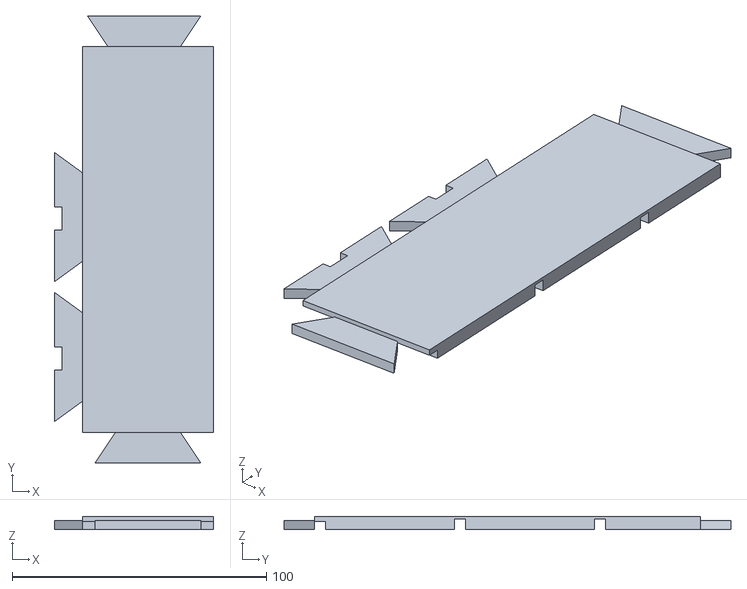
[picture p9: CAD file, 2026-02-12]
hardware/Brim y 51.5.stl
62.5 x 175.6 x 5.00

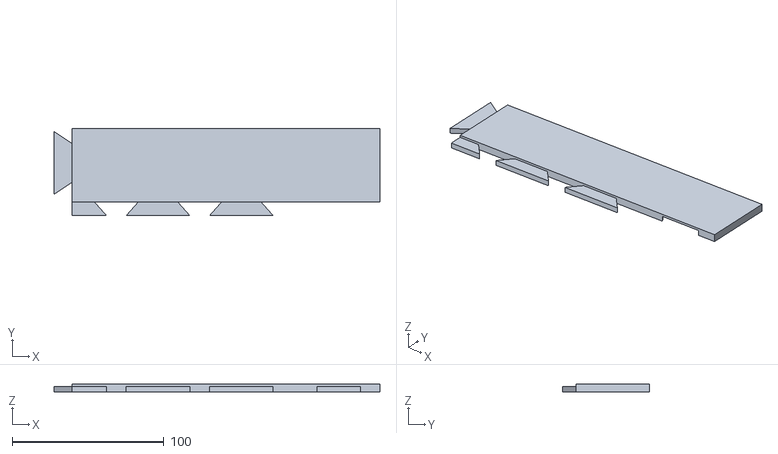
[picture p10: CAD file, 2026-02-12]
hardware/brim x 48.5.stl
215.2 x 57.5 x 5.00

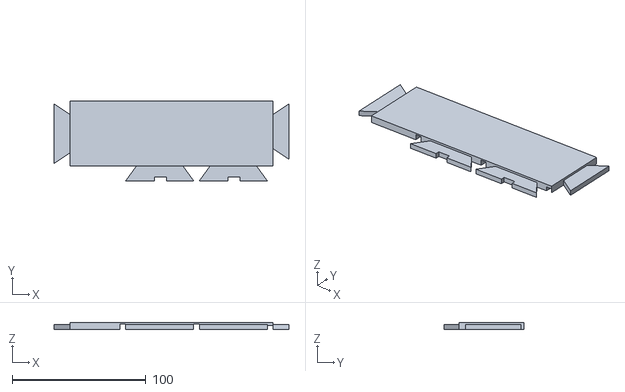
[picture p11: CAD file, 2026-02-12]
hardware/Brim y 48.5.stl
175.6 x 59.5 x 5.00

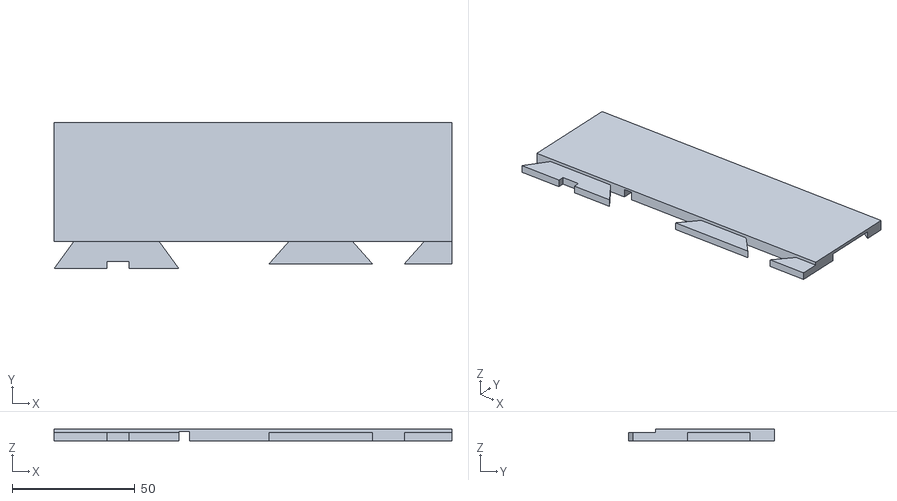
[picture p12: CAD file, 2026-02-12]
hardware/brim z 48.5.stl
161.8 x 59.5 x 5.00

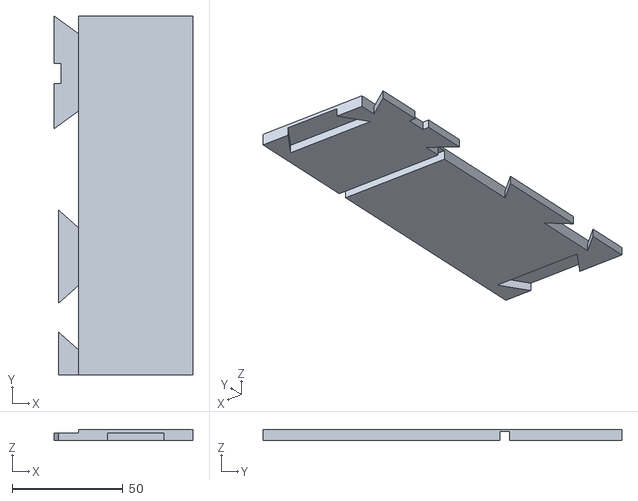
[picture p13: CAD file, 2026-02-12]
hardware/Brim z 51.5.stl
62.5 x 161.8 x 5.00

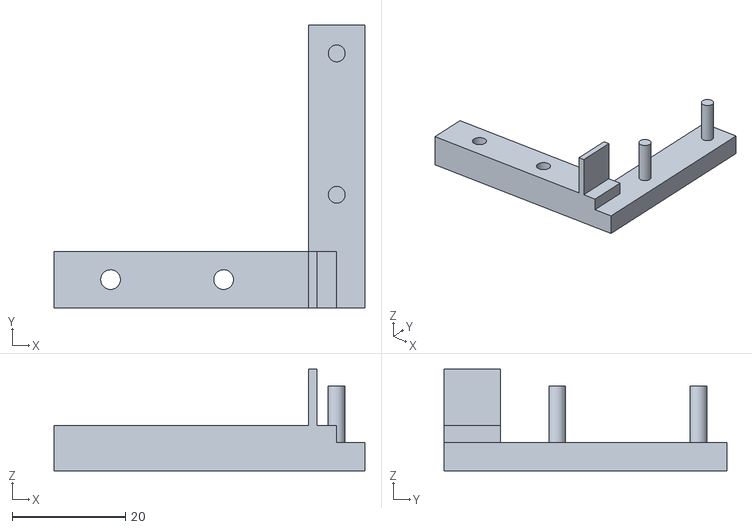
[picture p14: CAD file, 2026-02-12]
hardware/rail end 1.stl
55.0 x 50.0 x 18.0

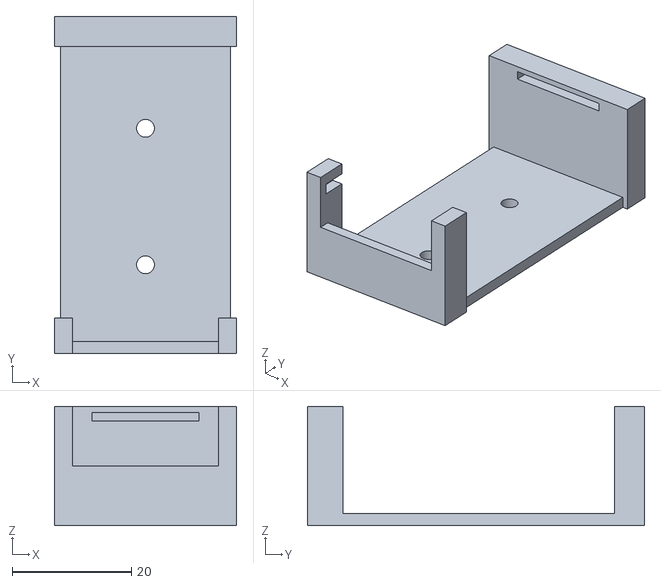
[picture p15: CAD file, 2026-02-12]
hardware/esp32_mount.stl
30.5 x 56.5 x 20.0

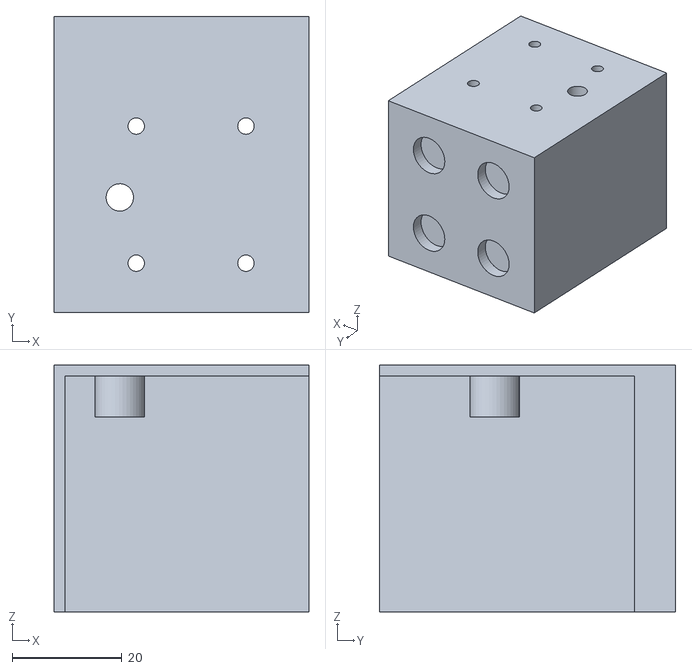
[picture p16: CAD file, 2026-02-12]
hardware/pulley_mount_2.stl
46.5 x 54.0 x 45.0

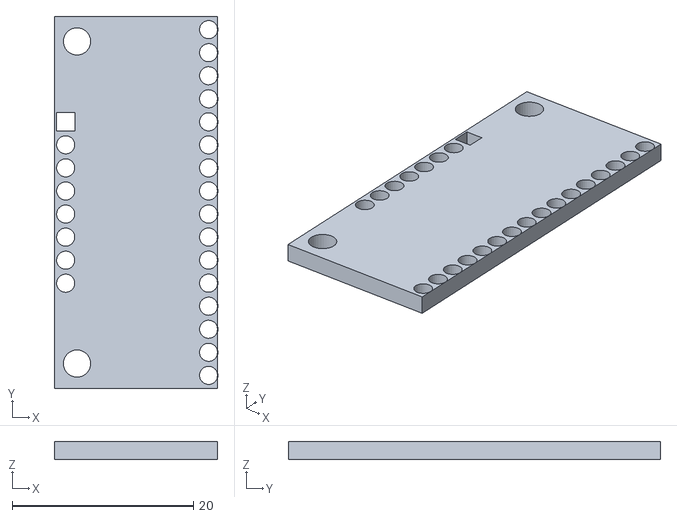
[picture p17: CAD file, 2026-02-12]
hardware/CD74HC4067 Holder.stl
18.0 x 41.0 x 2.00

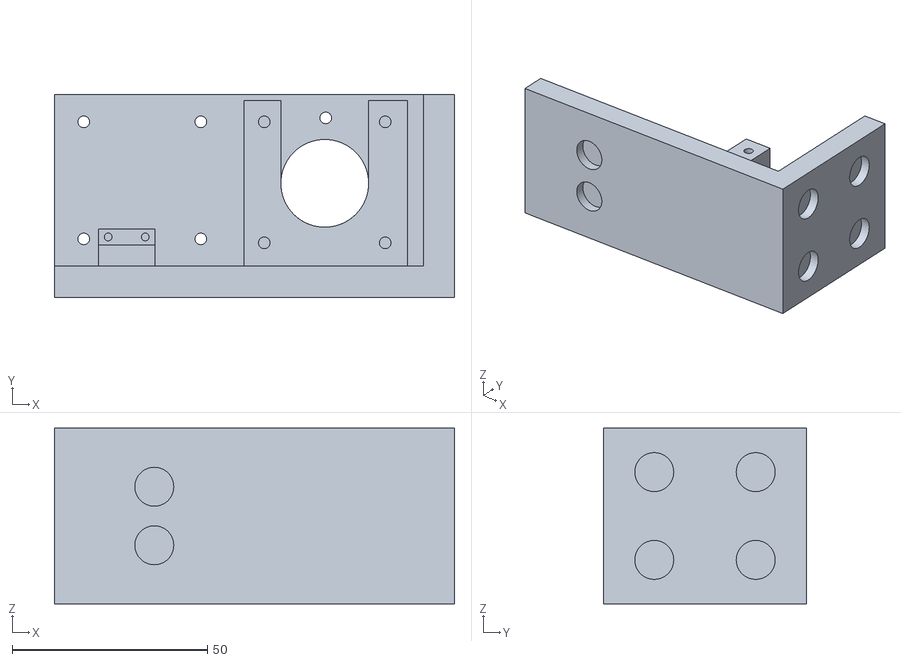
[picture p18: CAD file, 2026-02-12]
hardware/motor_mount_1.stl
102.5 x 52.0 x 45.0

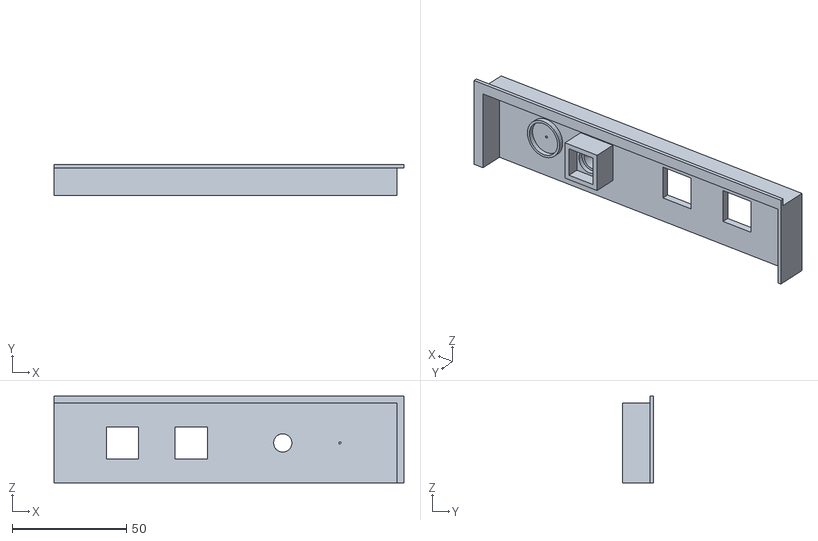
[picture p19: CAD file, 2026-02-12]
hardware/IOShield1.stl
153.0 x 13.5 x 38.0

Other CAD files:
hardware/top_end_2.stl
hardware/TopQuadrantD.stl
hardware/magnet_holder.stl
hardware/belt hodler v1.stl
hardware/IOShield2.stl
hardware/TopQuadrantA.stl
hardware/TopQuadrantB.stl
hardware/TopQuadrantC.stl
hardware/motor_mount_2.stl
hardware/pulley_mount_1.stl
hardware/rail end 2.stl
hardware/tmc2226_holder.stl
hardware/wcc_pieces.3mf

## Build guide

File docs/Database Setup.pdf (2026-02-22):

## Database Setup

Table 1: Users
Stores the unique identity of the people playing.
- user_id (Primary Key)
- username
- created_at
Table 2: UserSettings
Don't put settings in the Users table. By keeping them separate, you can add new features (like voice speed or magnet strength) without breaking the login logic.
- user_id (Foreign Key linked to Table 1)
- motor_speed (Fast/Medium/Slow)
- voice_enabled (True/False)
- ui_theme (Dark/Light)
Table 3: Games
Stores the metadata for a match.
- game_id
- white_user_id
- black_user_id (Could be "AI")
- start_time
- end_time
- result (White won / Black won / Draw) Table 4: MoveHistory
This is where the actual "film" of the game lives.
- move_id
- game_id (Foreign Key linked to Table 3)
- move_number
- notation (e.g., "e2e4")
- timestamp
Table 5: Graveyard
Which space on the side of the board is already occupied
- game_id
- side_space_coordinate
- occupied

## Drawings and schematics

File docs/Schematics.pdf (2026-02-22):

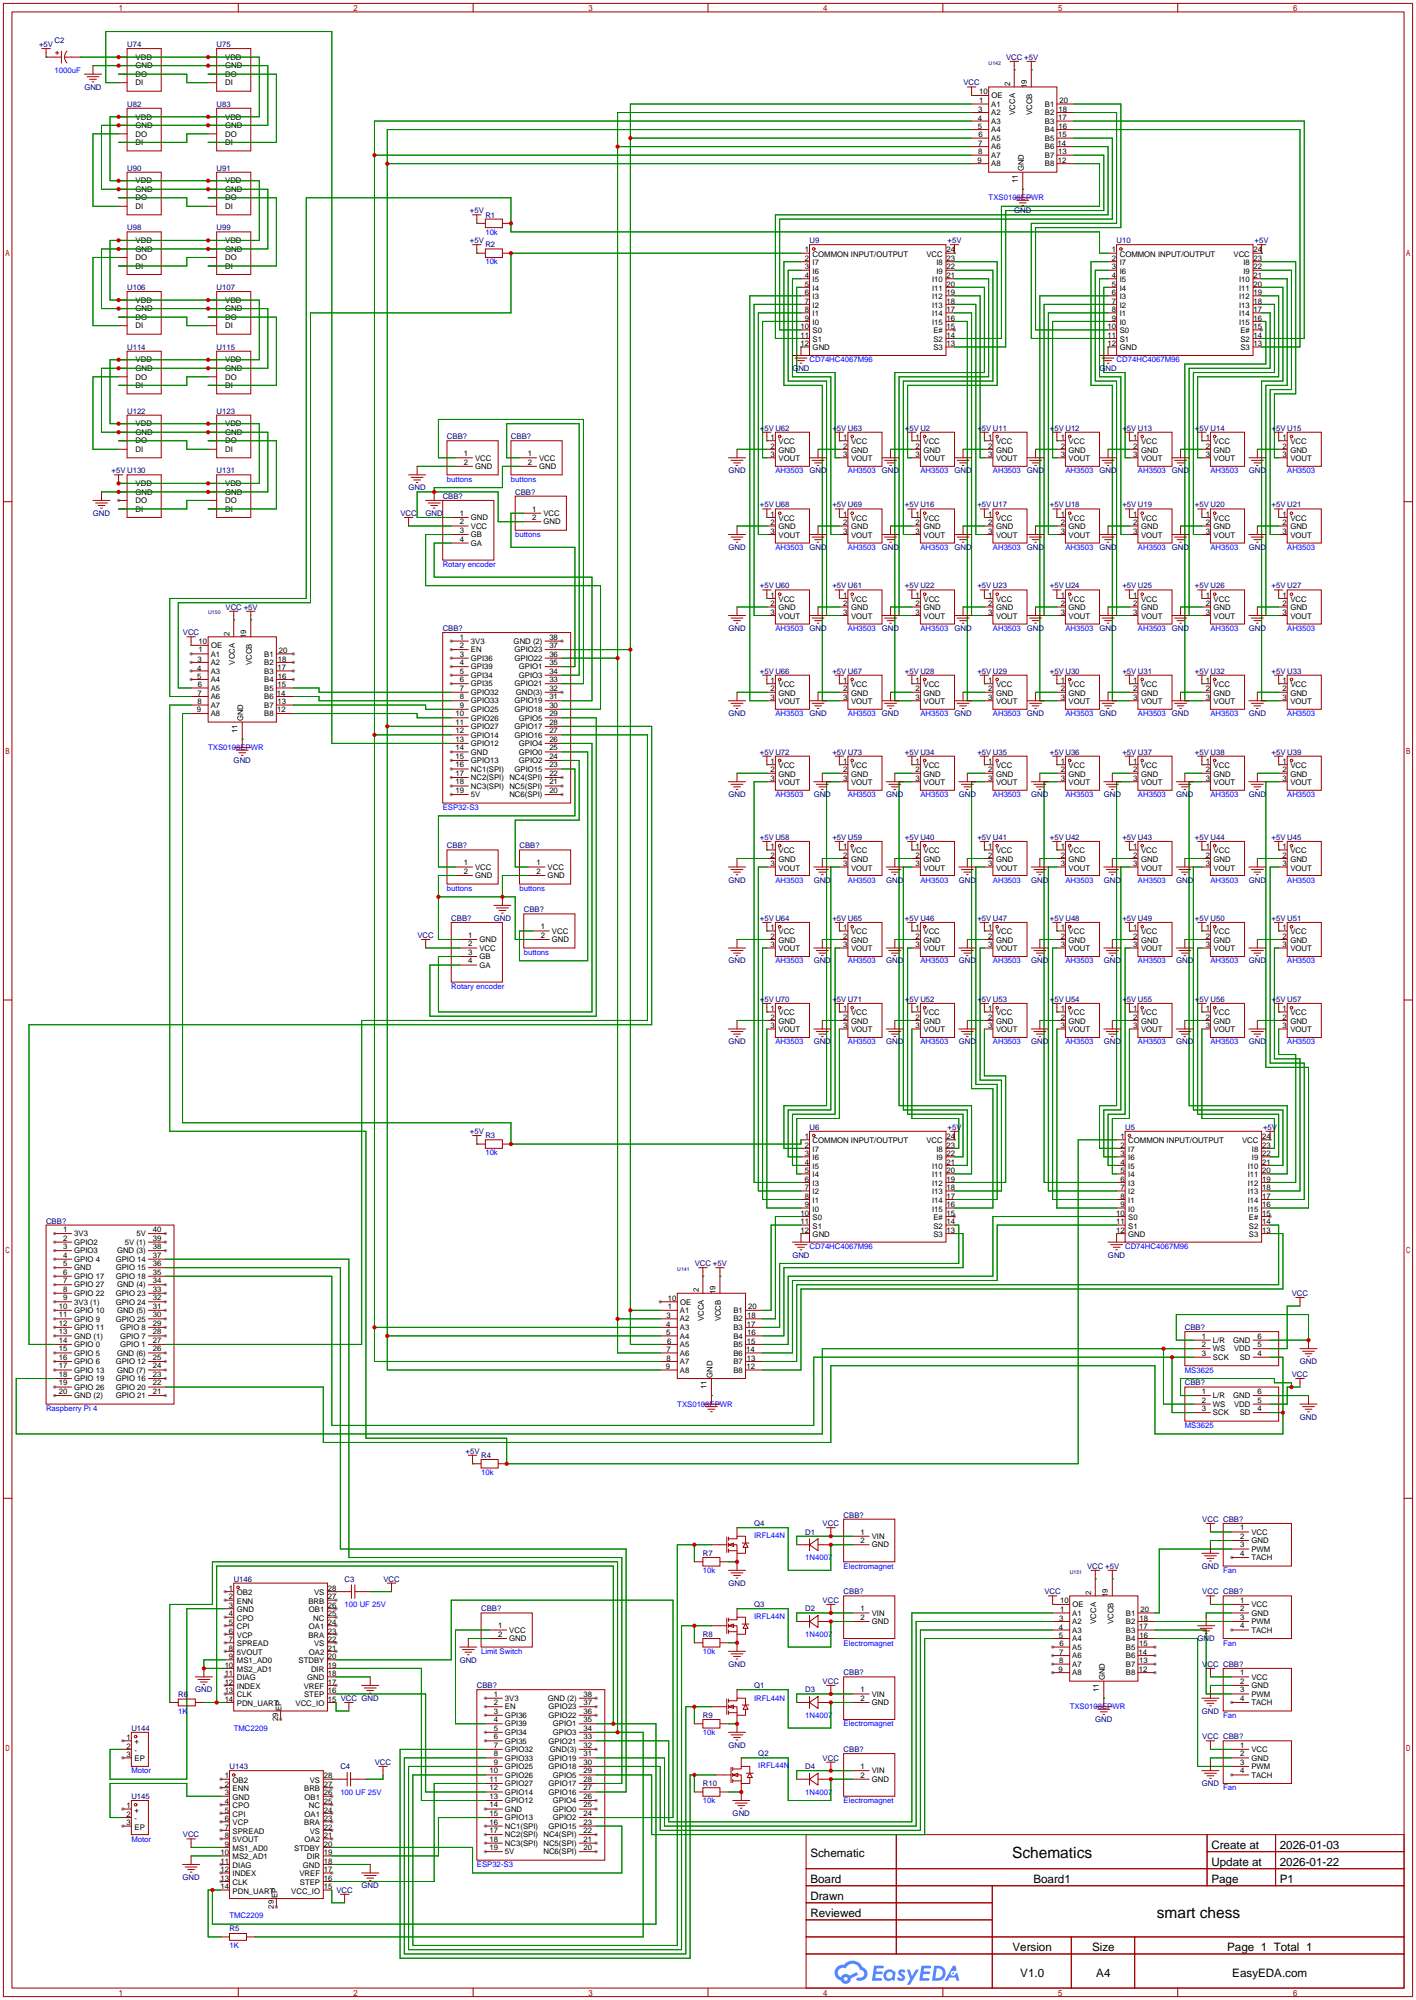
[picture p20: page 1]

GND | GND
DO DI | DO

DO DI | DO DI

Schematic | Schematics | Create at | 2026-01-03

Update at | 2026-01-22

Board | Board1 | Page | P1
Drawn | smart chess
Reviewed

Version | Size | Page 1 Total 1
V1.0 | A4 | EasyEDA.com

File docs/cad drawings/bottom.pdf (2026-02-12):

32 | 38 ²⁵, x20 A | A (1:3) B | B (1:3) C C (1:3) 9.15 160 149 | 40 58 | 29 65 55 23 | 20 13 171
52.5 36 20

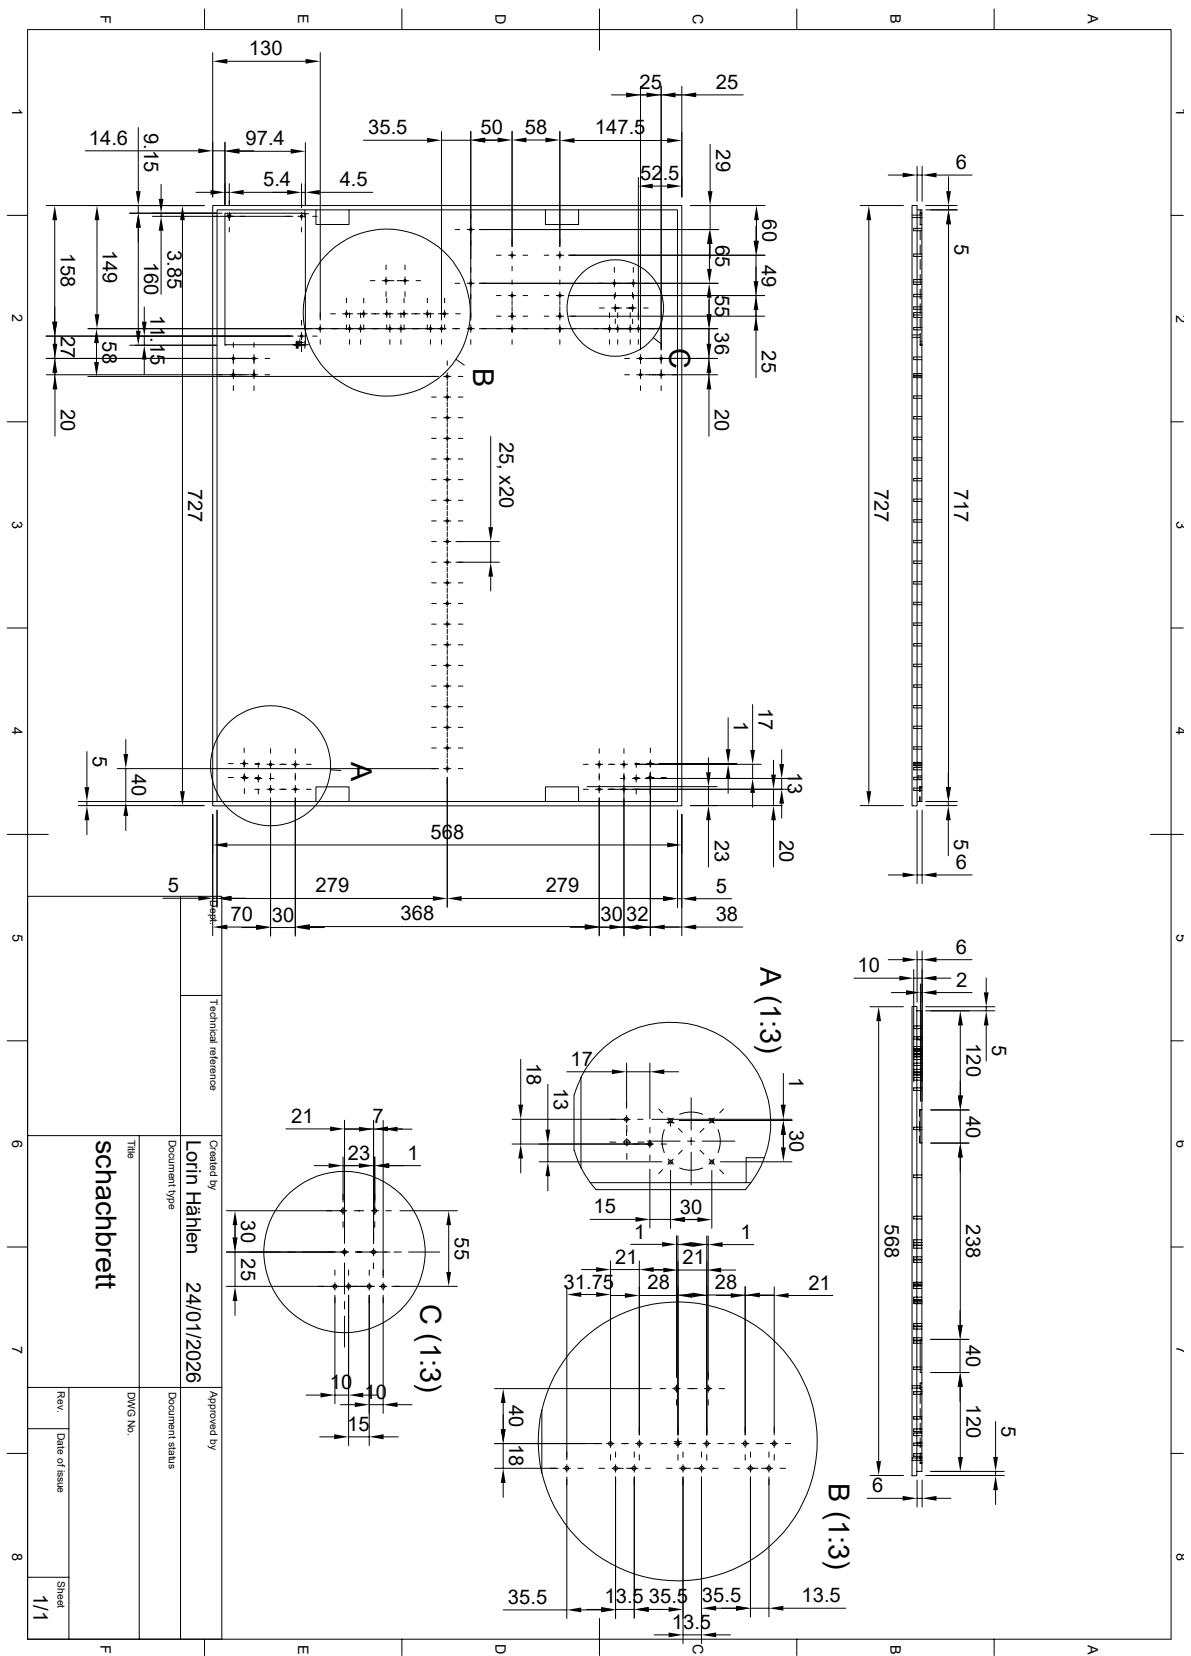
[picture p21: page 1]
568 ⁷²⁷

1 A 2 3 4 5 6 7 8 1 2 3 4 5 6 7 8 FEDCB FEDCBA Dept. Technical reference Created by Approved by Title DWG No. Document type Document status Rev. Date of issue Sheet 24/01/2026 1/1 schachbrett Lorin Hählen 717 5 5 727 568 120 40 238 40 120 2

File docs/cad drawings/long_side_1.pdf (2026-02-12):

56 6

12 | 35 | 15

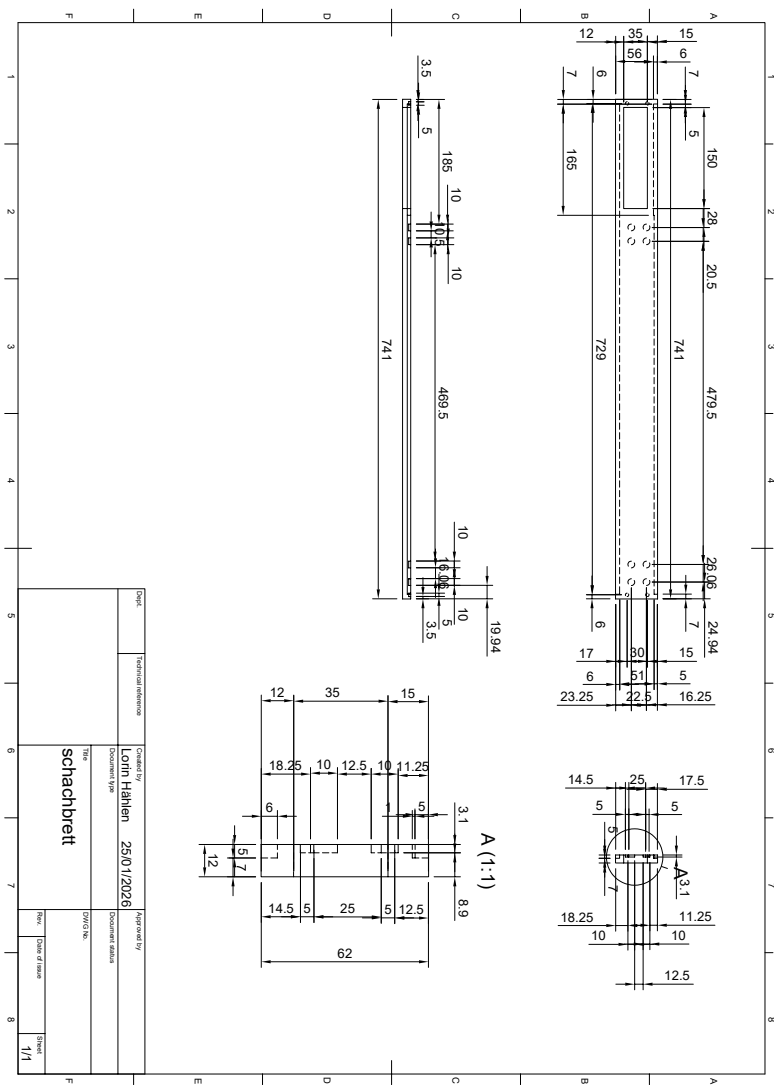
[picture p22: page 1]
17.5 ⁷⁴¹

1 A 2 3 4 5 6 7 8 1 2 3 4 5 6 7 8 FEDCB FEDCBA Dept. Technical reference Created by Approved by Title DWG No. Document type Document status Rev. Date of issue Sheet 25/01/2026 1/1 schachbrett Lorin Hählen 741 7 7 5 150 28 20.5 479.5 26.06 24.94 76 165 729 6

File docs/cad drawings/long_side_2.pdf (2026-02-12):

12 | 35 | 15562 7 7 5 6
3.1 | 8.9 1 | 5

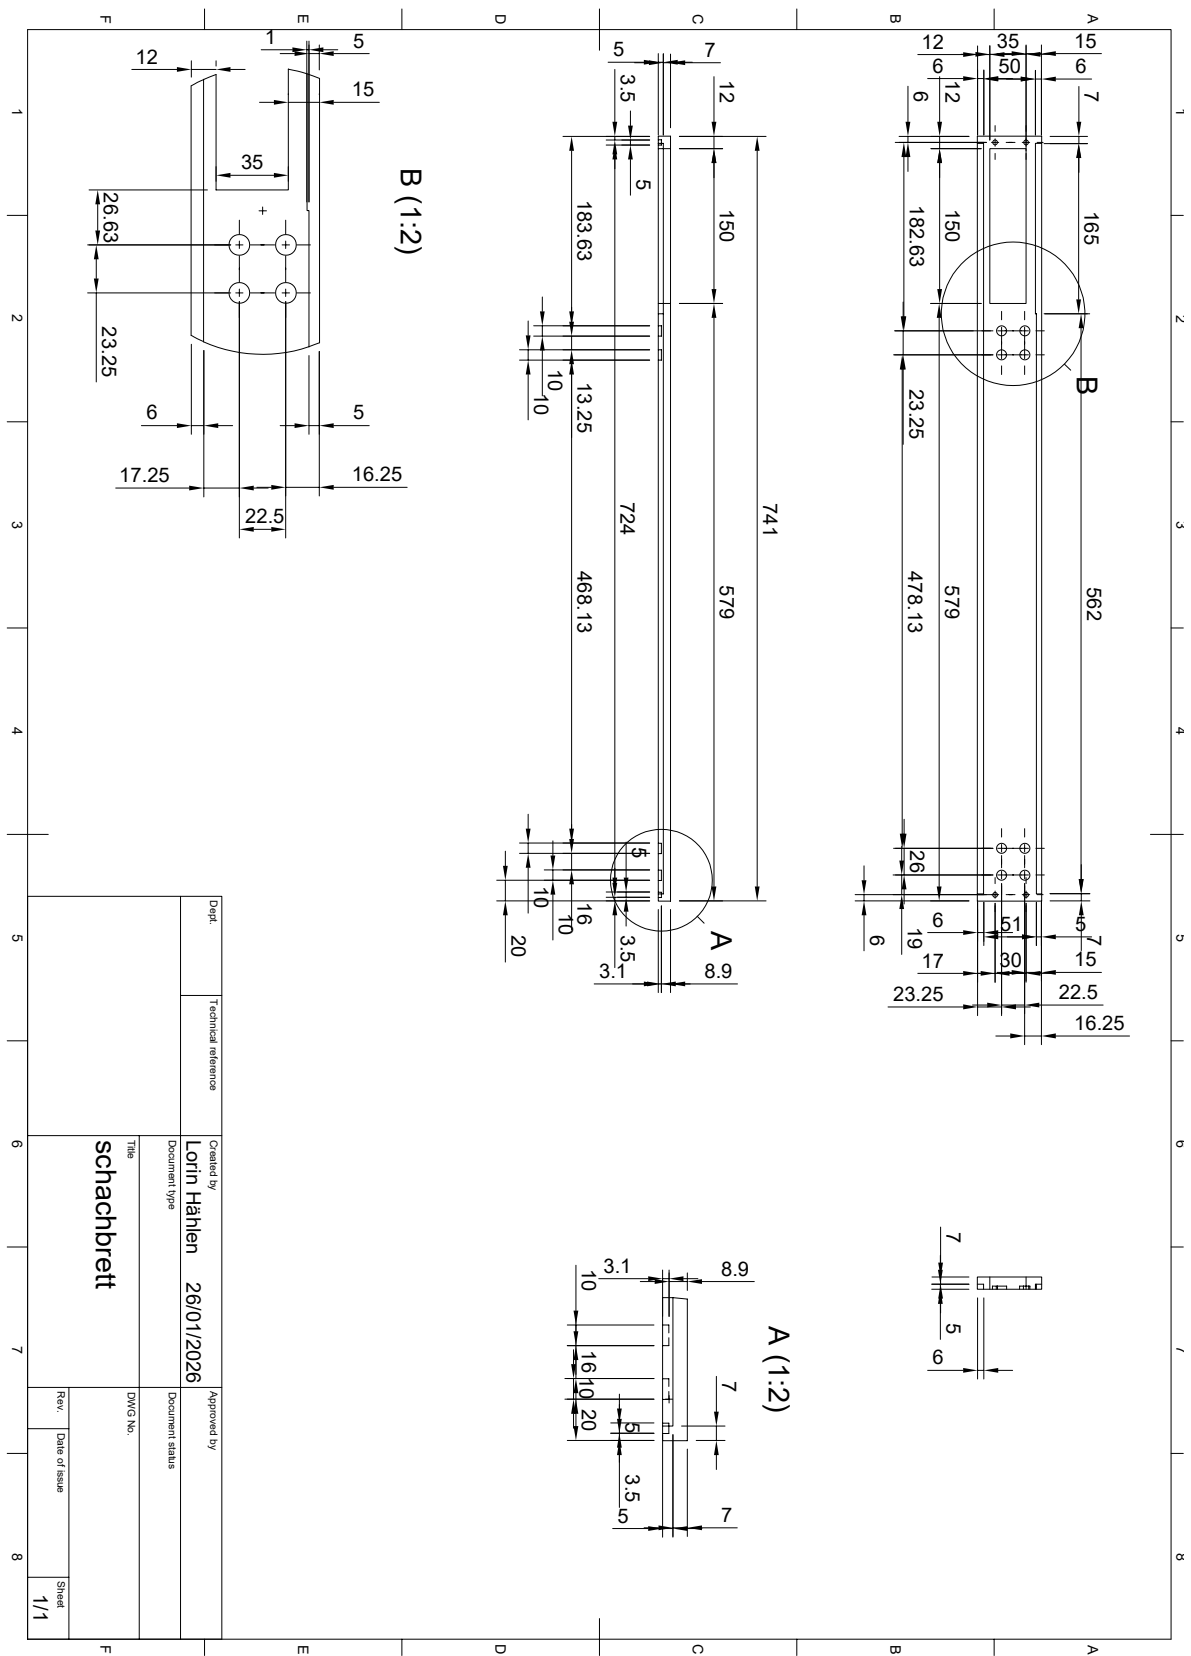
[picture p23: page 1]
5¹⁶⁵ ⁷ 6

1 A 2 3 4 5 6 7 8 1 2 3 4 5 6 7 8 FEDCB FEDCBA Dept. Technical reference Created by Approved by Title DWG No. Document type Document status Rev. Date of issue Sheet 26/01/2026 1/1 schachbrett Lorin Hählen 12 150 579 3.5 5 724 5 3.5 183.63 1013.25 10 468.13 10161020

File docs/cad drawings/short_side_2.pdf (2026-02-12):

10 | 40 | 12 ³.1 551.8 3.1 | 120 40 238.01 40 119.99 | A A (1:1) | 3.5 5 12 | 3.5
3.1 | 551.8 | 3.1

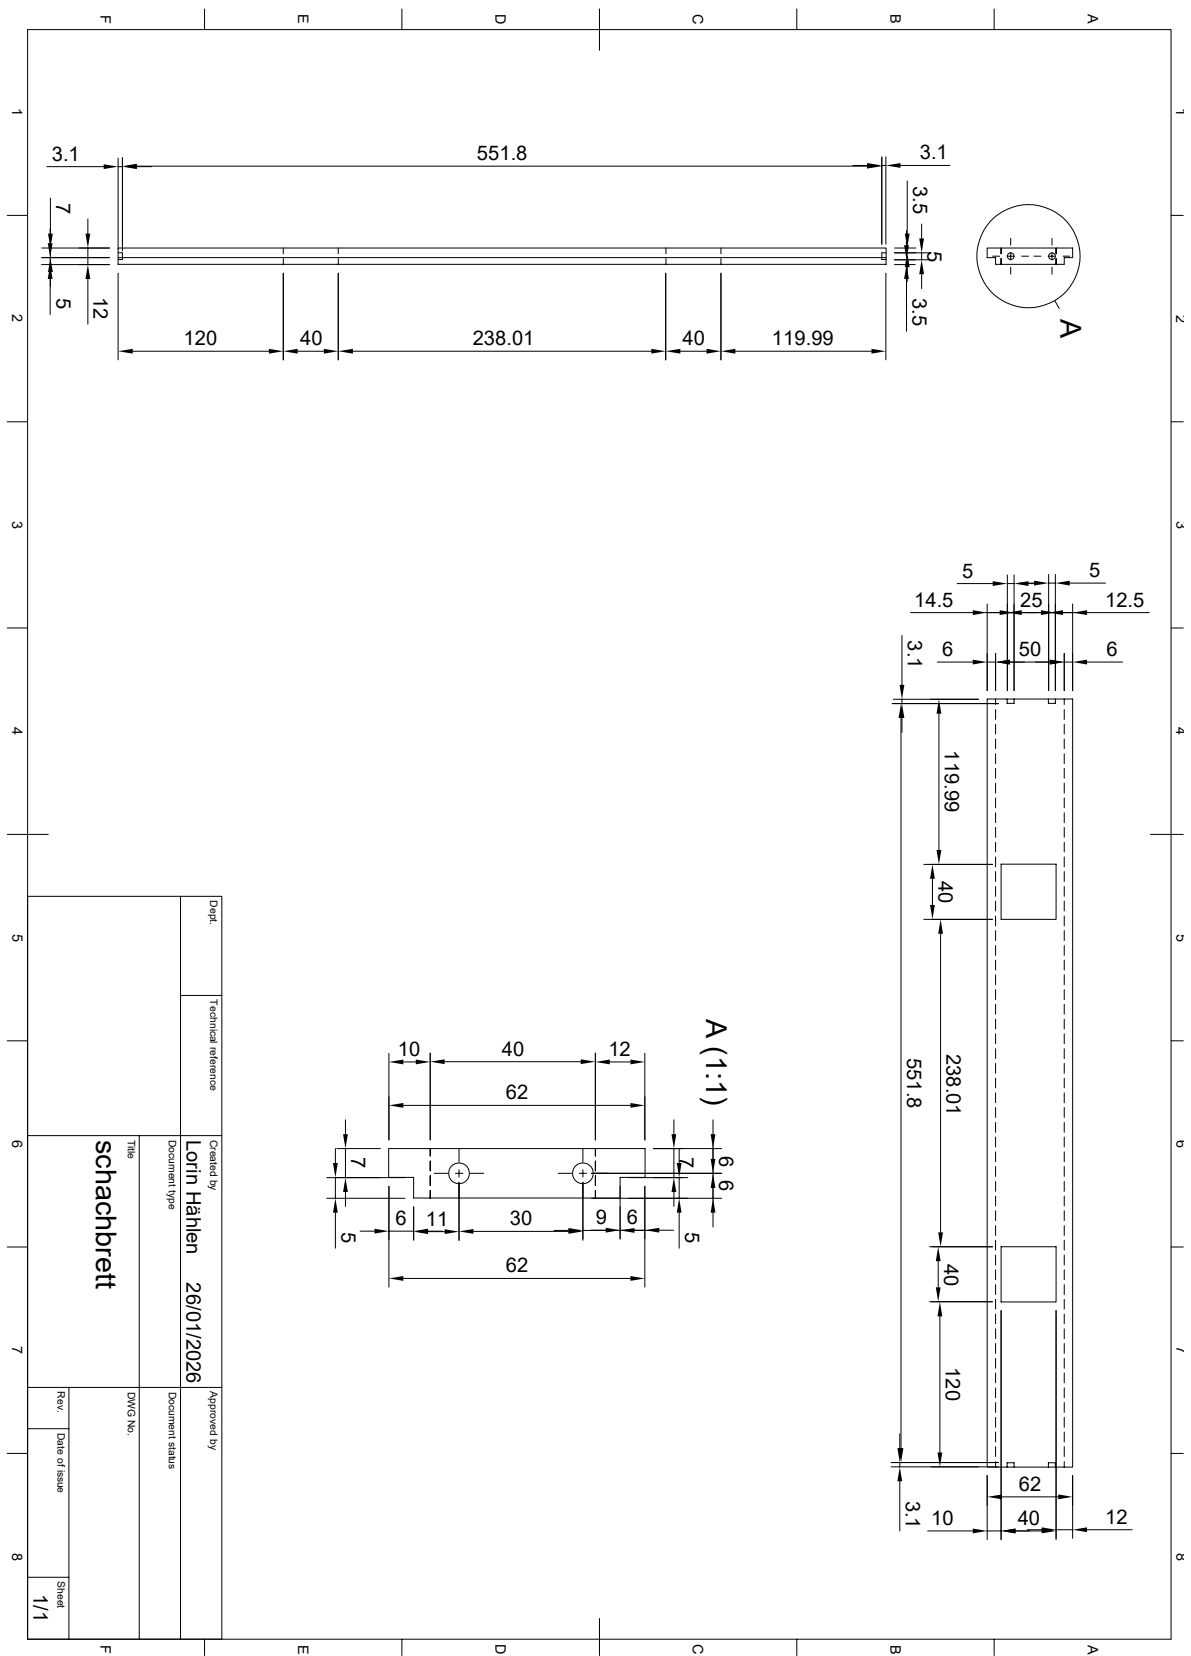
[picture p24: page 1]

1 A 2 3 4 5 6 7 8 1 2 3 4 5 6 7 8 FEDCB FEDCBA Dept. Technical reference Created by Approved by Title DWG No. Document type Document status Rev. Date of issue Sheet 26/01/2026 1/1 schachbrett Lorin Hählen 6 50 6

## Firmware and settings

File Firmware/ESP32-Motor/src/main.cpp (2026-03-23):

/**
 * ESP32 Motor Controller Firmware
 * 
 * Responsibilities:
 * - Control 2x TMC2226 stepper drivers for H-Bot gantry system
 * - Electromagnet control (4x electromagnets via MOSFETs)
 * - Limit switch homing
 * - PWM fan control (4x fans)
 * - Communicate with Raspberry Pi via UART (JSON protocol)
 * 
 * Hardware:
 * - ESP32-S3 DevKit C-1
 * - 2x TMC2226 stepper drivers
 * - 2x NEMA17 stepper motors (0.7A)
 * - 4x P25/20 electromagnets (12V)
 * - 4x IRFL44N MOSFETs for electromagnet switching
 * - 1x Limit switch (for homing)
 * - 4x Arctic S4028-6K fans (40mm, PWM)
 * - TXS0108E Level Shifter for fan PWM
 * 
 * H-Bot Kinematics:
 * - Both motors affect both X and Y
 * - Motor A forward + Motor B forward = Move +X
 * - Motor A forward + Motor B backward = Move +Y
 */

#include <Arduino.h>
#include <TMCStepper.h>
#include <ArduinoJson.h>

// ==================== PIN DEFINITIONS ====================

// TMC2226 Motor Drivers
// Motor A (X-axis component)
#define MOTOR_A_STEP_PIN    14
#define MOTOR_A_DIR_PIN     12
#define MOTOR_A_EN_PIN      0
#define MOTOR_A_TX_PIN      1   // ESP32 TX to TMC2226
#define MOTOR_A_RX_PIN      3   // ESP32 RX from TMC2226

// Motor B (Y-axis component)
#define MOTOR_B_STEP_PIN    27
#define MOTOR_B_DIR_PIN     13
#define MOTOR_B_EN_PIN      0
#define MOTOR_B_TX_PIN      1  // ESP32 TX to TMC2226
#define MOTOR_B_RX_PIN      3  // ESP32 RX from TMC2226

// Electromagnets (via MOSFETs, active HIGH)
#define MAGNET_1_PIN        26
#define MAGNET_2_PIN        25
#define MAGNET_3_PIN        33
#define MAGNET_4_PIN        32

// Limit switch (active LOW with pullup)
#define LIMIT_SWITCH_PIN    39

// PWM Fan control (via level shifter to 5V)
#define FAN_1_PIN           5
#define FAN_2_PIN           18
#define FAN_3_PIN           19
#define FAN_4_PIN           21

// UART communication with Raspberry Pi
#define UART_RX_PIN         16   // RX from Pi
#define UART_TX_PIN         17   // TX to Pi
#define UART_BAUD           115200

// ==================== MOTOR CONFIGURATION ====================

// TMC2226 UART addresses (set via MS1_AD0 and MS2_AD1 pins on driver)
#define MOTOR_A_ADDRESS     0b00  // Both MS pins LOW
#define MOTOR_B_ADDRESS     0b01  // MS1_AD0 HIGH, MS2_AD1 LOW

// Stepper motor specs
#define STEPS_PER_REV       200     // 1.8° stepper
#define MICROSTEPS          16      // TMC2226 microstepping
#define STEPS_PER_MM        80      // Steps per mm (configure based on pulley size)

// Speed settings (steps/second)
#define DEFAULT_SPEED       2000    // Default movement speed
#define MAX_SPEED           8000    // Maximum speed
#define HOMING_SPEED        500     // Slower speed for homing
#define ACCELERATION        2000    // Steps/second²

// Current limits (RMS current in mA)
#define MOTOR_CURRENT_RUN   500     // 0.7A * 0.707 ≈ 500mA RMS
#define MOTOR_CURRENT_HOLD  200     // Lower current when holding

// Board dimensions (in mm)
#define MAX_X_MM            560.0
#define MAX_Y_MM            560.0

// ==================== GLOBAL VARIABLES ====================

// Hardware Serial for TMC2226 communication
// Using Serial2 with separate TX and RX pins
HardwareSerial MotorSerial(2);  // Use UART2

// TMC2226 driver instances (2209 is the most complete library and should work)
TMC2209Stepper driverA(&MotorSerial, 0.11f, MOTOR_A_ADDRESS);
TMC2209Stepper driverB(&MotorSerial, 0.11f, MOTOR_B_ADDRESS);

// Current position (in steps)
long currentStepsX = 0;
long currentStepsY = 0;

// Current position (in mm)
float currentPosX = 0.0;
float currentPosY = 0.0;

// Target position
long targetStepsX = 0;
long targetStepsY = 0;

// Movement state
bool isMoving = false;
bool isHomed = false;

// Speed and acceleration
float currentSpeed = DEFAULT_SPEED;
unsigned long stepDelay = 1000000 / DEFAULT_SPEED; // microseconds

// Electromagnet states
bool magnetStates[4] = {false, false, false, false};

// JSON buffer
StaticJsonDocument<2048> jsonDoc;
String inputBuffer = "";

// Timing
unsigned long lastStepTime = 0;

// ==================== FUNCTION DECLARATIONS ====================

void setupPins();
void setupMotorDrivers();
void homeGantry();
void moveToAbsolute(float targetX, float targetY);
void moveRelative(float deltaX, float deltaY);
void stepMotors();
void calculateHBotSteps(long targetX, long targetY, long& stepsA, long& stepsB);
void setMagnet(int magnetIndex, bool state);
void setAllMagnets(bool state);
void setFanSpeed(int fanIndex, int pwmValue);
void processUARTCommand();
void sendStatus(const char* status, const char* message = nullptr);
void sendPositionUpdate();

// ==================== SETUP ====================

void setup() {
    // Initialize serial for debugging
    Serial.begin(115200);
    Serial.println("\n\n=== ESP32 Motor Controller Starting ===");
    
    // Initialize UART for Pi communication
    Serial1.begin(UART_BAUD, SERIAL_8N1, UART_RX_PIN, UART_TX_PIN);
    
    // Initialize UART for TMC2226 drivers (both share same UART bus)
    // Motor A TX connects to both drivers' PDN_UART via 1kΩ resistors
    // Motor A RX also connects (for reading back status)
    MotorSerial.begin(115200, SERIAL_8N1, MOTOR_A_RX_PIN, MOTOR_A_TX_PIN);
    
    // Setup hardware
    setupPins();
    setupMotorDrivers();
    
    Serial.println("Setup complete. Ready for commands.");
    
    // Send ready signal to Pi
    sendStatus("ready", "Motor controller initialized");
}

// ==================== MAIN LOOP ====================

void loop() {
    // Execute movement if in motion
    if (isMoving) {
        stepMotors();
    }
    
    // Process UART commands from Pi
    while (Serial1.available()) {
        char c = Serial1.read();
        
        if (c == '\n') {
            processUARTCommand();
            inputBuffer = "";
        } else {
            inputBuffer += c;
        }
    }
}

// ==================== PIN SETUP ====================

void setupPins() {
    // Motor control pins
    pinMode(MOTOR_A_STEP_PIN, OUTPUT);
    pinMode(MOTOR_A_DIR_PIN, OUTPUT);
    pinMode(MOTOR_A_EN_PIN, OUTPUT);
    
    pinMode(MOTOR_B_STEP_PIN, OUTPUT);
    pinMode(MOTOR_B_DIR_PIN, OUTPUT);
    pinMode(MOTOR_B_EN_PIN, OUTPUT);
    
    // Enable motors (active LOW)
    digitalWrite(MOTOR_A_EN_PIN, LOW);
    digitalWrite(MOTOR_B_EN_PIN, LOW);
    
    // Electromagnet pins
    pinMode(MAGNET_1_PIN, OUTPUT);
    pinMode(MAGNET_2_PIN, OUTPUT);
    pinMode(MAGNET_3_PIN, OUTPUT);
    pinMode(MAGNET_4_PIN, OUTPUT);
    
    // Ensure all magnets off
    setAllMagnets(false);
    
    // Limit switch
    pinMode(LIMIT_SWITCH_PIN, INPUT_PULLUP);
    
    // Fan PWM pins
    pinMode(FAN_1_PIN, OUTPUT);
    pinMode(FAN_2_PIN, OUTPUT);
    pinMode(FAN_3_PIN, OUTPUT);
    pinMode(FAN_4_PIN, OUTPUT);
    
    // Configure PWM for fans (25kHz, common for PC fans)
    ledcSetup(0, 25000, 8); // Channel 0, 25kHz, 8-bit resolution
    ledcSetup(1, 25000, 8);
    ledcSetup(2, 25000, 8);
    ledcSetup(3, 25000, 8);
    
    ledcAttachPin(FAN_1_PIN, 0);
    ledcAttachPin(FAN_2_PIN, 1);
    ledcAttachPin(FAN_3_PIN, 2);
    ledcAttachPin(FAN_4_PIN, 3);
    
    // Start fans at 50% speed
    for (int i = 0; i < 4; i++) {
        setFanSpeed(i, 128);
    }
    
    Serial.println("Pins configured");
}

// ==================== TMC2226 SETUP ====================

void setupMotorDrivers() {
    Serial.println("Configuring TMC2226 drivers...");
    
    // Driver A configuration
    driverA.begin();
    driverA.toff(5);                    // Enable driver
    driverA.rms_current(MOTOR_CURRENT_RUN); // Set RMS current
    driverA.microsteps(MICROSTEPS);     // Set microstepping
    driverA.pwm_autoscale(true);        // Enable automatic current scaling
    driverA.en_spreadCycle(false);      // Use StealthChop (quieter)
    
    // Driver B configuration
    driverB.begin();
    driverB.toff(5);
    driverB.rms_current(MOTOR_CURRENT_RUN);
    driverB.microsteps(MICROSTEPS);
    driverB.pwm_autoscale(true);
    driverB.en_spreadCycle(false);
    
    Serial.println("TMC2226 drivers configured");
    
    // Test: Read back configuration
    Serial.print("Driver A current: ");
    Serial.println(driverA.rms_current());
    Serial.print("Driver B current: ");
    Serial.println(driverB.rms_current());
}

// ==================== HOMING ====================

void homeGantry() {
    Serial.println("Starting homing sequence...");
    
    isHomed = false;
    
    // Move towards limit switch until triggered
    // Assuming limit switch is at (0, 0)
    
    digitalWrite(MOTOR_A_DIR_PIN, LOW);  // Reverse direction
    digitalWrite(MOTOR_B_DIR_PIN, LOW);
    
    // Move slowly until limit switch triggers
    while (digitalRead(LIMIT_SWITCH_PIN) == HIGH) {
        // Step both motors
        digitalWrite(MOTOR_A_STEP_PIN, HIGH);
        digitalWrite(MOTOR_B_STEP_PIN, HIGH);
        delayMicroseconds(5);
        digitalWrite(MOTOR_A_STEP_PIN, LOW);
        digitalWrite(MOTOR_B_STEP_PIN, LOW);
        delayMicroseconds(1000000 / HOMING_SPEED);
    }
    
    Serial.println("Limit switch triggered");
    
    // Back off slightly
    digitalWrite(MOTOR_A_DIR_PIN, HIGH);
    digitalWrite(MOTOR_B_DIR_PIN, HIGH);
    
    for (int i = 0; i < 100; i++) {
        digitalWrite(MOTOR_A_STEP_PIN, HIGH);
        digitalWrite(MOTOR_B_STEP_PIN, HIGH);
        delayMicroseconds(5);
        digitalWrite(MOTOR_A_STEP_PIN, LOW);
        digitalWrite(MOTOR_B_STEP_PIN, LOW);
        delayMicroseconds(1000000 / HOMING_SPEED);
    }
    
    // Set current position as (0, 0)
    currentStepsX = 0;
    currentStepsY = 0;
    currentPosX = 0.0;
    currentPosY = 0.0;
    
    isHomed = true;
    
    Serial.println("Homing complete");
    sendStatus("homed", "Gantry homed to (0, 0)");
}

// ==================== MOVEMENT ====================

void moveToAbsolute(float targetX, float targetY) {
    if (!isHomed) {
        Serial.println("ERROR: Cannot move - not homed");
        sendStatus("error", "Gantry not homed");
        return;
    }
    
    // Constrain to board limits
    targetX = constrain(targetX, 0, MAX_X_MM);
    targetY = constrain(targetY, 0, MAX_Y_MM);
    
    Serial.print("Moving to (");
    Serial.print(targetX);
    Serial.print(", ");
    Serial.print(targetY);
    Serial.println(")");
    
    // Convert mm to steps
    targetStepsX = (long)(targetX * STEPS_PER_MM);
    targetStepsY = (long)(targetY * STEPS_PER_MM);
    
    isMoving = true;
}

void moveRelative(float deltaX, float deltaY) {
    moveToAbsolute(currentPosX + deltaX, currentPosY + deltaY);
}

void stepMotors() {
    // Calculate remaining distance
    long remainingX = targetStepsX - currentStepsX;
    long remainingY = targetStepsY - currentStepsY;
    
    // Check if we've reached target
    if (remainingX == 0 && remainingY == 0) {
        isMoving = false;
        sendPositionUpdate();
        Serial.println("Movement complete");
        return;
    }
    
    // Calculate H-Bot motor directions
    // H-Bot kinematics:
    // Motor A: controls X + Y diagonal
    // Motor B: controls X - Y diagonal
    //
    // To move +X: A forward, B forward
    // To move +Y: A forward, B backward
    
    long stepsA = remainingX + remainingY;  // A motor steps
    long stepsB = remainingX - remainingY;  // B motor steps
    
    // Set motor directions
    digitalWrite(MOTOR_A_DIR_PIN, stepsA > 0 ? HIGH : LOW);
    digitalWrite(MOTOR_B_DIR_PIN, stepsB > 0 ? HIGH : LOW);
    
    // Step motors
    unsigned long currentTime = micros();
    if (currentTime - lastStepTime >= stepDelay) {
        // Step motor A if needed
        if (stepsA != 0) {
            digitalWrite(MOTOR_A_STEP_PIN, HIGH);
            delayMicroseconds(5);
            digitalWrite(MOTOR_A_STEP_PIN, LOW);
            currentStepsX += (stepsA > 0) ? 1 : -1;
        }
        
        // Step motor B if needed
        if (stepsB != 0) {
            digitalWrite(MOTOR_B_STEP_PIN, HIGH);
            delayMicroseconds(5);
            digitalWrite(MOTOR_B_STEP_PIN, LOW);
            // Y component is difference in motor steps
            if (stepsA == 0) {
                currentStepsY += (stepsB > 0) ? -1 : 1;
            } else {
                currentStepsY += (remainingY > 0) ? 1 : -1;
            }
        }
        
        // Update current position in mm
        currentPosX = (float)currentStepsX / STEPS_PER_MM;
        currentPosY = (float)currentStepsY / STEPS_PER_MM;
        
        lastStepTime = currentTime;
    }
}

// ==================== ELECTROMAGNET CONTROL ====================

void setMagnet(int magnetIndex, bool state) {
    if (magnetIndex < 0 || magnetIndex >= 4) return;
    
    int pins[] = {MAGNET_1_PIN, MAGNET_2_PIN, MAGNET_3_PIN, MAGNET_4_PIN};
    
    digitalWrite(pins[magnetIndex], state ? HIGH : LOW);
    magnetStates[magnetIndex] = state;
    
    Serial.print("Magnet ");
    Serial.print(magnetIndex + 1);
    Serial.println(state ? " ON" : " OFF");
}

void setAllMagnets(bool state) {
    for (int i = 0; i < 4; i++) {
        setMagnet(i, state);
    }
}

// ==================== FAN CONTROL ====================

void setFanSpeed(int fanIndex, int pwmValue) {
    if (fanIndex < 0 || fanIndex >= 4) return;
    
    pwmValue = constrain(pwmValue, 0, 255);
    ledcWrite(fanIndex, pwmValue);
    
    Serial.print("Fan ");
    Serial.print(fanIndex + 1);
    Serial.print(" speed: ");
    Serial.println(pwmValue);
}

// ==================== UART COMMAND PROCESSING ====================

void processUARTCommand() {
    // Parse JSON command
    DeserializationError error = deserializeJson(jsonDoc, inputBuffer);
    
    if (error) {
        Serial.print("JSON parse error: ");
        Serial.println(error.c_str());
        return;
    }
    
    JsonObject cmd = jsonDoc.as<JsonObject>();
    const char* cmdType = cmd["cmd"];
    
    if (cmdType == nullptr) {
        Serial.println("No 'cmd' field in JSON");
        return;
    }
    
    // Route command
    if (strcmp(cmdType, "home") == 0) {
        homeGantry();
    }
    else if (strcmp(cmdType, "move_absolute") == 0) {
        float x = cmd["x"] | 0.0;
        float y = cmd["y"] | 0.0;
        
        if (cmd.containsKey("speed")) {
            currentSpeed = cmd["speed"];
            stepDelay = 1000000 / currentSpeed;
        }
        
        moveToAbsolute(x, y);
    }
    else if (strcmp(cmdType, "move_relative") == 0) {
        float dx = cmd["dx"] | 0.0;
        float dy = cmd["dy"] | 0.0;
        moveRelative(dx, dy);
    }
    else if (strcmp(cmdType, "magnet_on") == 0) {
        if (cmd.containsKey("magnet")) {
            int magnet = cmd["magnet"];
            setMagnet(magnet - 1, true);
        } else {
            setAllMagnets(true);
        }
    }
    else if (strcmp(cmdType, "magnet_off") == 0) {
        if (cmd.containsKey("magnet")) {
            int magnet = cmd["magnet"];
            setMagnet(magnet - 1, false);
        } else {
            setAllMagnets(false);
        }
    }
    else if (strcmp(cmdType, "set_fan") == 0) {
        int fan = cmd["fan"] | 1;
        int speed = cmd["speed"] | 128;
        setFanSpeed(fan - 1, speed);
    }
    else if (strcmp(cmdType, "stop") == 0) {
        isMoving = false;
        targetStepsX = currentStepsX;
        targetStepsY = currentStepsY;
        sendStatus("stopped", "Movement stopped");
    }
    else if (strcmp(cmdType, "get_position") == 0) {
        sendPositionUpdate();
    }
    else {
        Serial.print("Unknown command: ");
        Serial.println(cmdType);
    }
}

// ==================== STATUS REPORTING ====================

void sendStatus(const char* status, const char* message) {
    jsonDoc.clear();
    jsonDoc["type"] = "status";
    jsonDoc["status"] = status;
    jsonDoc["controller"] = "motor";
    
    if (message) {
        jsonDoc["message"] = message;
    }
    
    serializeJson(jsonDoc, Serial1);
    Serial1.println();
}

void sendPositionUpdate() {
    jsonDoc.clear();
    jsonDoc["type"] = "position";
    jsonDoc["x"] = currentPosX;
    jsonDoc["y"] = currentPosY;
    jsonDoc["homed"] = isHomed;
    
    serializeJson(jsonDoc, Serial1);
    Serial1.println();
}

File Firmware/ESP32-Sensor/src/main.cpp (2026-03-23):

/**
 * ESP32 Sensor Controller Firmware
 * 
 * Responsibilities:
 * - Scan 64 Hall Effect sensors via 4x CD74HC4067 multiplexers
 * - Control 64 WS2812B LEDs for board visualization
 * - Read 6 buttons and 2 rotary encoders
 * - Communicate with Raspberry Pi via UART (JSON protocol)
 * 
 * Hardware:
 * - ESP32-S3 DevKit C-1
 * - 4x CD74HC4067 16:1 Analog Multiplexers
 * - 64x AH3503 Hall Effect Sensors (digital, active LOW)
 * - 64x WS2812B RGB LEDs
 * - 6x Buttons
 * - 2x Rotary Encoders (with button)
 * - 2x TXS0108E Level Shifters (3.3V <-> 5V)
 */

#include <Arduino.h>
#include <Adafruit_NeoPixel.h>
#include <ArduinoJson.h>

// ==================== PIN DEFINITIONS ====================

// Multiplexer control pins (shared by all 4 multiplexers)
#define MUX_S0_PIN    23
#define MUX_S1_PIN    22
#define MUX_S2_PIN    27
#define MUX_S3_PIN    14

// Multiplexer enable/output pins (one per multiplexer)
#define MUX_EN_PIN    0  // Enable (active LOW)
#define MUX1_OUT_PIN  32  // Multiplexer 1 output (rows 0-1)
#define MUX2_OUT_PIN  33  // Multiplexer 2 output (rows 2-3)
#define MUX3_OUT_PIN  25  // Multiplexer 3 output (rows 4-5)
#define MUX4_OUT_PIN  26  // Multiplexer 4 output (rows 6-7)

// LED control
#define LED_DATA_PIN  22
#define LED_COUNT     81  // 9x9 grid (4 LEDs per square, shared corners)
#define LED_GRID_SIZE 9   // 9x9 physical LED grid

// Buttons (active LOW with internal pullup)
#define BTN1_PIN      25
#define BTN2_PIN      26
#define BTN3_PIN      27
#define BTN4_PIN      32
#define BTN5_PIN      33
#define BTN6_PIN      34

// Rotary Encoders
#define ENC1_A_PIN    35
#define ENC1_B_PIN    36
#define ENC1_BTN_PIN  39

#define ENC2_A_PIN    14
#define ENC2_B_PIN    12
#define ENC2_BTN_PIN  13

// UART communication with Raspberry Pi
#define UART_RX_PIN   1   // RX from Pi
#define UART_TX_PIN   3   // TX to Pi
#define UART_BAUD     115200

// ==================== CONSTANTS ====================

#define BOARD_SIZE    8
#define SCAN_INTERVAL_MS    100   // Scan sensors every 100ms
#define BUTTON_DEBOUNCE_MS  50    // Button debounce time
#define LED_BRIGHTNESS      128   // Default brightness (0-255)

// ==================== GLOBAL VARIABLES ====================

// Sensor state (8x8 matrix, true = piece detected)
bool sensorState[BOARD_SIZE][BOARD_SIZE];
bool lastSensorState[BOARD_SIZE][BOARD_SIZE];

// LED control
Adafruit_NeoPixel strip(LED_COUNT, LED_DATA_PIN, NEO_GRB + NEO_KHZ800);

// Button states
bool buttonStates[6] = {false};
bool lastButtonStates[6] = {false};
unsigned long lastButtonPress[6] = {0};

// Rotary encoder states
volatile int encoder1Position = 0;
volatile int encoder2Position = 0;
int lastEncoder1Position = 0;
int lastEncoder2Position = 0;

// Timing
unsigned long lastScanTime = 0;

// JSON buffer
StaticJsonDocument<2048> jsonDoc;
String inputBuffer = "";

// LED theme/colors
struct LEDTheme {
    uint32_t backgroundColor;
    uint32_t whitePieceColor;
    uint32_t blackPieceColor;
    uint32_t highlightColor;
    uint32_t legalMoveColor;
} currentTheme;

// ==================== FUNCTION DECLARATIONS ====================

void setupPins();
void setupLEDs();
void scanSensors();
void readButtons();
void sendSensorUpdate();
void sendButtonEvent(int buttonIndex, bool pressed);
void sendEncoderEvent(int encoderIndex, int delta);
void processUARTCommand();
void handleLEDCommand(JsonObject& cmd);
void handleConfigCommand(JsonObject& cmd);
void setLEDSquare(int file, int rank, uint32_t color);
void updateLEDs();
uint8_t readMultiplexer(uint8_t muxIndex, uint8_t channel);
void IRAM_ATTR encoder1ISR();
void IRAM_ATTR encoder2ISR();

// ==================== SETUP ====================

void setup() {
    // Initialize serial for debugging
    Serial.begin(115200);
    Serial.println("\n\n=== ESP32 Sensor Controller Starting ===");
    
    // Initialize UART for Pi communication
    Serial1.begin(UART_BAUD, SERIAL_8N1, UART_RX_PIN, UART_TX_PIN);
    
    // Setup hardware
    setupPins();
    setupLEDs();
    
    // Initialize sensor state to all empty
    memset(sensorState, 0, sizeof(sensorState));
    memset(lastSensorState, 0, sizeof(lastSensorState));
    
    // Set default LED theme
    currentTheme.backgroundColor = strip.Color(0, 0, 0);        // Black
    currentTheme.whitePieceColor = strip.Color(255, 255, 255);  // White
    currentTheme.blackPieceColor = strip.Color(100, 100, 100);  // Gray
    currentTheme.highlightColor = strip.Color(0, 255, 0);       // Green
    currentTheme.legalMoveColor = strip.Color(0, 100, 255);     // Blue
    
    Serial.println("Setup complete. Ready for commands.");
    
    // Send ready signal to Pi
    StaticJsonDocument<128> readyMsg;
    readyMsg["type"] = "status";
    readyMsg["status"] = "ready";
    readyMsg["controller"] = "sensor";
    serializeJson(readyMsg, Serial1);
    Serial1.println();
}

// ==================== MAIN LOOP ====================

void loop() {
    unsigned long currentTime = millis();
    
    // Scan sensors at regular interval
    if (currentTime - lastScanTime >= SCAN_INTERVAL_MS) {
        scanSensors();
        lastScanTime = currentTime;
    }
    
    // Read buttons
    readButtons();
    
    // Check for encoder changes
    if (encoder1Position != lastEncoder1Position) {
        int delta = encoder1Position - lastEncoder1Position;
        sendEncoderEvent(1, delta);
        lastEncoder1Position = encoder1Position;
    }
    
    if (encoder2Position != lastEncoder2Position) {
        int delta = encoder2Position - lastEncoder2Position;
        sendEncoderEvent(2, delta);
        lastEncoder2Position = encoder2Position;
    }
    
    // Process UART commands from Pi
    while (Serial1.available()) {
        char c = Serial1.read();
        
        if (c == '\n') {
            processUARTCommand();
            inputBuffer = "";
        } else {
            inputBuffer += c;
        }
    }
}

// ==================== PIN SETUP ====================
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

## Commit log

2026-02-06 First Draft for Firmware. A lot of things are still wrong. particualarly the LED logic and pin numbers.
    [main.cpp]
2026-02-06 fixed LED Layout (not 8x8 but 9x9), fixed Motor drivers UART communication (now correctly using the seperated rx and tx on a shared bus) and now using the right platform for the specific esp in regar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
    [main.cpp]
2026-02-12 added some 3d files and technical documentations
    [Brim x 51.5.stl, Brim y 48.5.stl, Brim y 51.5.stl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]
2026-02-12 fixed the brim
    [Brim x 51.5.stl, Brim y 48.5.stl, Brim y 51.5.stl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]
2026-02-22 added better documentation
    [brim.3mf, top_end_1.stl, top_end_2.stl]
